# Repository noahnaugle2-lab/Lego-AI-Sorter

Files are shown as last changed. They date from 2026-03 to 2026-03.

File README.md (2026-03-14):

# LEGO AI Sorting Machine v3 / v4 Hybrid

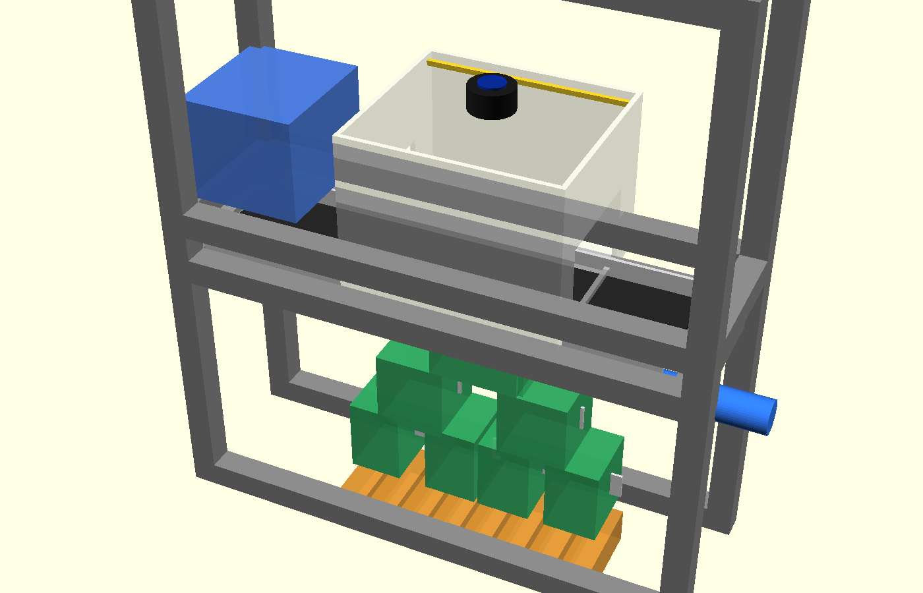
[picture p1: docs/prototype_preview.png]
Prototype Preview


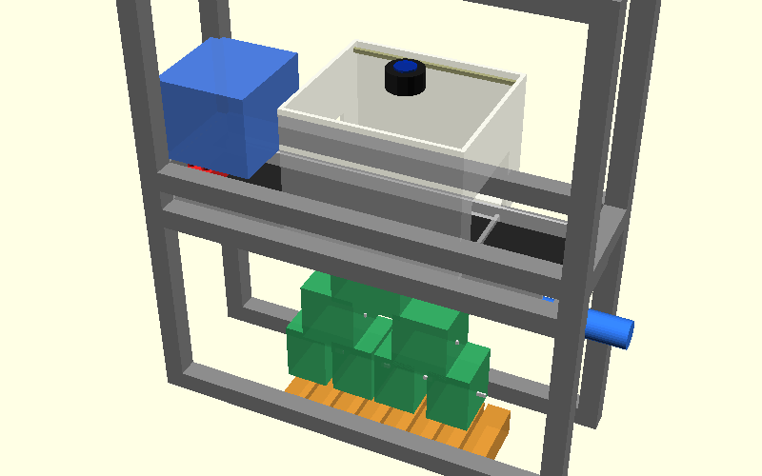
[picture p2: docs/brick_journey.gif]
Brick Journey


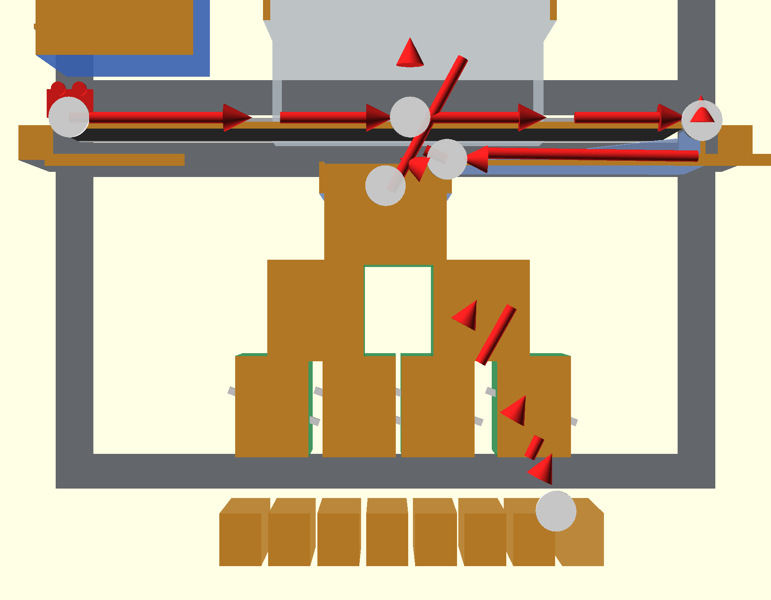
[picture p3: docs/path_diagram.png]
Brick Path Diagram


An AI-powered LEGO brick sorting machine built on a Raspberry Pi 5. Combines computer vision, a Brickognize REST API, a local learning cache, and a binary gate tree to automatically classify and route bricks into output bins in real time.

---

## v4 Hybrid Design

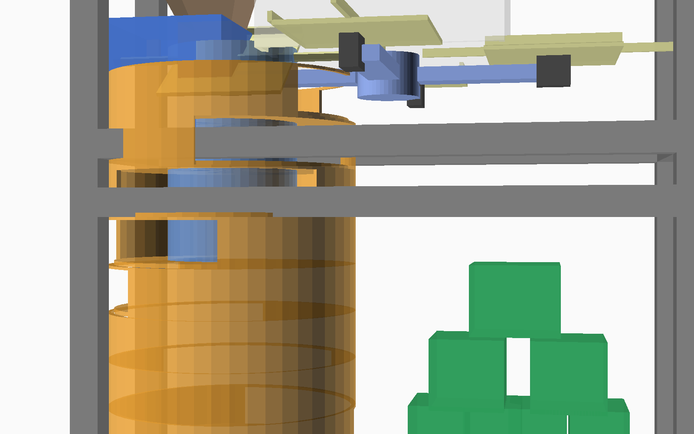
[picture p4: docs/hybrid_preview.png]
Hybrid Assembly Preview


The v4 Hybrid combines the best mechanical ideas from two independent designs into one cohesive machine:

### What's new vs v3

| Subsystem | v3 (original) | v4 Hybrid |
|---|---|---|
| **Input** | Linear NEMA 17 belt | 4-platform rotating carousel |
| **Singulation** | Manual separation | Step feeder hopper (automatic) |
| **Entry transition** | 5.5° gravity ramp (insufficient) | Carousel tilt-to-dispense (active, no ramp) |
| **Distribution** | 31-servo 5-level binary tree (32 bins) | Pancake stack (8 categories) + 3-level mini-tree (8 sub-bins) = 64 destinations |
| **Servo count** | 31 gates | 15 total (4 tilt + 1 trap-door + 10 mini-tree) |
| **Brick size limit** | Informal | 80mm sphere constraint (covers 98% of LEGO production pieces) |

### Carousel Feeder (`carousel.py`, `3d-parts/carousel_feeder.scad`)

A 4-platform rotating carousel replaces the linear belt. All four positions process simultaneously (pipelined):

```
Position 0 — LOAD      ← step feeder deposits one brick
Position 1 — IMAGE     ← fixed camera captures, AI classifies
Position 2 — DISPENSE  ← platform tilts ~45°, brick drops to pancake stack
Position 3 — CLEAR     ← platform returns flat, ready for next brick
```

One 90° rotation advances all platforms by one stage. Effective throughput: ~1 brick per rotation cycle (2–3 s). Each platform has an 80mm × 80mm acrylic insert compatible with the 80mm sphere size constraint that encompasses 98% of production LEGO pieces.

### Pancake Stack Distribution (`pancake_sorter.py`, `3d-parts/pancake_stack.scad`)

A central rotating chute distributes bricks to stacked circular bin levels — one servo per level, one level per category:

```
Level 0 — Bricks    Level 4 — Minifigs
Level 1 — Plates    Level 5 — Slopes
Level 2 — Tiles     Level 6 — Special
Level 3 — Technic   Level 7 — Unknown/Review
```

Below each stack level, a 3-level mini gate tree sub-sorts by part size/variant into 8 output bins. Total: **64 unique destinations** with only **15 servos** (vs 31 in v3).

### What's kept from v3

- Brickognize AI classifier + local HSV histogram cache
- Flask web dashboard + SQLite inventory
- Confidence-based routing (review bin / unknown bin)
- Raspberry Pi 5 target hardware + PCA9685 servo drivers
- All existing sort modes (`part`, `color`, `category`, `set`)

### New files

| File | Purpose |
|---|---|
| `carousel.py` | Carousel feeder motor + platform tilt servos |
| `pancake_sorter.py` | Pancake stack chute + mini gate tree routing |
| `3d-parts/carousel_feeder.scad` | Printable carousel (hub + arms + platforms) |
| `3d-parts/pancake_stack.scad` | Printable bin stack + rotating chute |
| `3d-parts/hybrid_assembly.scad` | Full assembly visualisation |

---

---

## Table of Contents

- [v4 Hybrid Design](#v4-hybrid-design)
- [Quick Start](#quick-start)
- [Architecture Overview](#architecture-overview)
- [Project Structure](#project-structure)
- [Modules & Features](#modules--features)
  - [main.py — Orchestrator](#mainpy--orchestrator)
  - [conveyor.py — Belt Motor Control](#conveyorpy--belt-motor-control)
  - [scanner.py — Camera & Motion Detection](#scannerpy--camera--motion-detection)
  - [classifier.py — AI Classification](#classifierpy--ai-classification)
  - [sorter.py — Binary Gate Tree](#sorterpy--binary-gate-tree)
  - [inventory.py — SQLite Database](#inventorypy--sqlite-database)
  - [web_ui.py — Flask Dashboard](#web_uipy--flask-dashboard)
  - [logger.py — Structured Logging](#loggerpy--structured-logging)
- [Sort Modes](#sort-modes)
- [Confidence Routing](#confidence-routing)
- [Web Dashboard](#web-dashboard)
- [API Reference](#api-reference)
- [Configuration](#configuration)
- [Error Recovery](#error-recovery)
- [Testing](#testing)
- [Hardware Requirements](#hardware-requirements)
- [Auto-Start on Boot](#auto-start-on-boot)

---

## Quick Start

### 1. Install dependencies
```bash
pip install -r requirements.txt --break-system-packages
```

On Raspberry Pi, also install hardware libraries:
```bash
pip install RPi.GPIO adafruit-circuitpython-pca9685 adafruit-circuitpython-motor --break-system-packages
```

### 2. Configure
Edit `config.yaml` to match your hardware:
- GPIO pin numbers for stepper motor and LEDs
- PCA9685 I2C addresses
- Belt speed and encoder settings
- Confidence thresholds
- Bin assignments for part categories
- Sort mode (`part`, `color`, `category`, `set`)

### 3. Test components individually
```bash
# Test camera capture
python main.py --test-camera

# Test classification on a photo
python main.py --test-classify photo_of_brick.jpg

# Test all servo gates
python main.py --test-gates

# Start web dashboard without hardware (simulation mode)
python main.py --web-only

# Start with color sorting mode
python main.py --sort-mode color
```

### 4. Run the full system
```bash
python main.py
```

Web dashboard available at `http://<pi-ip>:5000`

### 5. Run tests
```bash
python -m pytest tests/ -v
```

---

## Architecture Overview

```
Motion Detected
    ↓
[Scanner] Pause Belt → Capture Frames → Select Sharpest → Crop Brick
    ↓
[Classifier] Check Local Cache ──► Cache Hit → Return Cached Result
    ↓ Cache Miss
[Brickognize API] POST JPEG → Parse Response (part_id, color, confidence)
    ↓ Low Confidence (optional rescan)
[Main] Advance Belt → Capture 2nd Angle → Reclassify
    ↓
[Confidence Routing]
  ├─ High (≥0.65) → [Sorter] Binary Gate Tree → Correct Bin
  ├─ Mid  (0.45–0.65) → Review Bin (30)
  └─ Low  (<0.45)     → Unknown Bin (31)
    ↓
[Inventory] Log Part → Update Set Tracking → Hourly Stats
    ↓
[Web Dashboard] Real-time Display & Controls
```

Three threads run concurrently:
- **Main thread**: Flask web server
- **Sorting loop**: Motion → Classify → Sort pipeline
- **Retry loop**: API recovery — reclassifies queued items every 30 seconds

---

## Project Structure
```
lego-sorter/
├── main.py              # Entry point and orchestrator
├── config.yaml          # All configuration and bin assignments
├── conveyor.py          # Stepper motor belt control (with encoder feedback)
├── scanner.py           # Camera capture + motion detection (multi-angle)
├── classifier.py        # Brickognize API + local learning cache
├── sorter.py            # Binary gate tree + multi-sort-mode routing
├── inventory.py         # SQLite database + Rebrickable + analytics + export
├── web_ui.py            # Flask web dashboard + OTA config + REST API
├── logger.py            # Structured JSON logging with file rotation
├── lego-sorter.service  # systemd unit file for auto-start
├── templates/
│   └── dashboard.html   # Responsive single-page dashboard (Bootstrap)
├── tests/
│   ├── test_sorter.py      # Gate tree routing and sort mode tests
│   ├── test_classifier.py  # Cache, confidence, and category tests
│   └── test_inventory.py   # Database, stats, and export tests
├── logs/
│   └── sorter.log       # Rotating JSON log files (auto-created)
├── requirements.txt
└── README.md
```

---

## Modules & Features

### main.py — Orchestrator

The central controller (`SortingMachine` class) that wires all subsystems together.

**Features:**
- Starts and coordinates all subsystems (conveyor, scanner, classifier, sorter, inventory, web UI)
- Manages graceful shutdown on SIGINT/SIGTERM
- **Auto-rescan**: If classification confidence is low, the belt advances slightly and a second image is captured automatically; tracks rescan success rate
- **API Retry Queue**: Holds up to 20 failed classifications in memory; a background thread retries every 30 seconds when the API recovers
- **OTA Configuration**: Applies runtime config changes (belt speed, thresholds, LED brightness) from the web dashboard without restarting
- **Power Sequencing**: Controls servo power relay via GPIO 22 (enabled on init, disabled on shutdown to prevent brown-out)
- Simulation mode: All hardware interfaces fall back to no-ops when RPi libraries are unavailable

---

### conveyor.py — Belt Motor Control

Controls the conveyor belt stepper motor with optional closed-loop feedback.

**Features:**
- Drives a **NEMA 17 stepper motor** via a **TMC2209** driver (step/dir/enable GPIO pins)
- Configurable belt speed (5–100 mm/s), dynamically adjustable at runtime
- **Closed-loop encoder feedback** (optional):
  - Reads a rotary encoder (channels A/B) via GPIO interrupts
  - Measures actual belt speed from pulses-per-revolution and roller circumference
  - Proportional speed correction (Kp = 0.3) adjusts step delays every 250 ms
- **Pause/Resume**: Stops belt during scanning, resumes after classification (configurable pause delay, default 300 ms)
- Thread-safe pause/resume lock for coordination with sorting loop

---

### scanner.py — Camera & Motion Detection

Handles image capture, motion detection, and brick isolation.

**Features:**
- Supports **Pi Camera Module 3** (primary, up to 1920×1080) and an optional secondary USB camera for multi-angle classification
- **Motion detection**: Frame differencing with Gaussian blur and pixel threshold — triggers belt pause and capture when a brick enters the scanning chamber
- **Background reference frame**: Captured at startup and refreshable via the dashboard API (`/api/control/update_background`)
- **Best-frame selection**: Captures a configurable number of frames and selects the sharpest using Laplacian variance
- **Auto-exposure warmup**: Discards first 30 frames at startup to stabilize camera exposure
- **Brick cropping**: Contour detection with configurable padding to isolate the brick in the frame
- **LED control**: PWM-controlled LED strip (GPIO 12, 1000 Hz) with configurable brightness (0–100%)
- **MJPEG streaming**: Provides live video feed endpoints for the web dashboard

---

### classifier.py — AI Classification

Identifies bricks using the Brickognize REST API and a local learning cache.

**Brickognize API:**
- POSTs JPEG images to `https://api.brickognize.com/predict/`
- Returns: `part_id`, `part_name`, `color`, `confidence` (0–1), and up to 3 alternative matches
- Timeout: 10 seconds; 2 automatic retries on failure with 1-second delays
- Supports multi-angle classification (secondary image improves confidence)

**Local Learning Cache:**
- Avoids API calls for previously seen bricks
- Signature: **HSV color histogram** (8×8×4 bins, 256 buckets) + **aspect ratio**
- Similarity: Bhattacharyya coefficient (70% histogram + 30% aspect ratio)
- **Auto-learns** API results with confidence ≥ 0.85
- **Manual corrections** from the Review tab stored with confidence = 1.0
- Persistence: JSON file on disk; FIFO eviction when cache exceeds 200 entries
- Match threshold: 0.90 similarity required to use a cached result

**Confidence Routing:**
- High (≥ 0.65): Auto-sort to correct bin
- Mid (0.45–0.65): Route to review bin (30) for human verification
- Low (< 0.45): Route to unknown bin (31)

**Category Extraction:**
- 65 keyword patterns covering detailed LEGO taxonomy (bricks, plates, tiles, technic, slopes, arches, etc.)
- Specificity-ordered matching (e.g., "Brick 2x4" matched before generic "Brick")
- Fallback: "Other" category for unrecognized parts

**Statistics tracked:** total classifications, successes, failures, review count, accuracy rate, cache hits/misses

---

### sorter.py — Binary Gate Tree

Routes bricks through a physical binary gate tree into one of 32 bins.

**Hardware:**
- **31 servo gates** across **2× PCA9685** 16-channel PWM boards (I2C: 0x40, 0x41)
- Top 3 levels (7 gates): **MG90S** metal-gear servos (higher torque, durable)
- Bottom 2 levels (24 gates): **SG90** micro servos (cost-effective)
- Configurable pulse widths per servo type and settle time (default 120 ms)

**Gate Tree:**
- 5-level binary tree: Level 0 (root, 1 gate) → Level 4 (16 gates) = 31 total gates, 32 leaf bins
- Routing: Binary decomposition of the bin number determines left/right path at each level
- Gates 0–15 on board 1, gates 16–30 on board 2

**Sort Modes:**
| Mode | Routing Logic |
|---|---|
| **Part** (default) | Keyword-matched part type → `bin_assignments` in config |
| **Color** | `COLOR_BIN_MAP` — 32 named colors mapped to specific bins |
| **Category** | Broad groups: bricks→0, plates→1, tiles→2, technic→4, slopes→5, etc. |
| **Set** | Parts needed for a target LEGO set get priority bins; others go to overflow |

**Bin Management:**
- Per-bin part count tracking; warns at 50+ items per bin
- Gate actuation counter per gate; logs maintenance warning at 10,000 actuations
- Individual or full bin reset via dashboard API

---

### inventory.py — SQLite Database

Persistent storage for all sort history, analytics, and set tracking.

**Database Tables:**
| Table | Purpose |
|---|---|
| `sorted_parts` | Full history: part_id, name, color, bin, confidence, timestamp |
| `set_inventories` | Rebrickable set part lists (part_id, color, quantity needed/found) |
| `sets` | Set metadata: name, year, total part count |
| `sort_history` | Hourly aggregated counts for analytics charts |
| `corrections` | Reclassification feedback log (old bin → new bin) |

**Statistics:**
- Total sorted, identified, unique parts, average confidence
- Throughput: parts/minute (last 10 min), parts/hour, parts/day, peak hour, session duration
- Confidence distribution histogram (10 buckets, 0–100%)
- Top 10 categories and top 10 colors (last 10 entries)
- Review parts list (needs_review flag)

**Rebrickable Integration:**
- Fetches set part lists via paginated Rebrickable API (100 parts/page)
- Tracks parts found vs. quantity needed per set
- Reports completion percentage per target set

**Export Formats:**
- **BrickLink CSV**: Part ID, Color, Quantity
- **Rebrickable CSV**: Part, Color, Quantity
- **Missing Parts CSV**: Parts still needed to complete a specific set

---

### web_ui.py — Flask Dashboard

Single-page web application for monitoring and controlling the machine.

**Dashboard Tab:**
- Live MJPEG camera feed (primary + optional secondary)
- Current machine state: running / idle / classifying / scanning / sorting
- Recent 30 sorted parts with part name, color, bin, and timestamp
- Real-time stats: total sorted, identified, unique parts, accuracy
- Bin status panel: highlights bins at or above capacity (≥50 items)
- Set tracking: shows completion progress for target LEGO sets
- Controls: Start / Stop / Pause / Resume
- Belt speed slider (5–100 mm/s)
- Sort mode selector (Part / Color / Category / Set)
- Inventory CSV export button

**Analytics Tab:**
- Throughput metrics: last-hour count, 24-hour count, peak hour, avg/hour, session duration
- Sort history bar chart: hourly counts over the last 24 hours
- Confidence distribution histogram
- Top 10 categories and top 10 colors

**Review Tab:**
- Lists all parts flagged for manual verification
- Sortable by part name, confidence, or timestamp
- One-click bin reassignment — feedback is saved to the local learning cache

**Settings Tab:**
- Belt speed, confidence threshold, review threshold, LED brightness
- Changes applied live and persisted to `config.yaml` (no restart required)
- Sensitive keys (API keys, secrets) are protected from web-based editing

---

### logger.py — Structured Logging

**Features:**
- Hierarchical loggers: root `sorter` with per-module children (`sorter.classifier`, etc.)
- Console output: color-coded by level (DEBUG cyan, INFO green, WARNING yellow, ERROR red)
- File output: JSON-formatted entries for machine parsing
- Rotating file handler: 5 MB per file, 5 backup files, written to `logs/sorter.log`
- Contextual metadata fields: `part_id`, `confidence`, `bin_number`, `category`, `color`, etc.
- Auto-creates `logs/` directory on first run

---

## Sort Modes

Switchable at runtime from the dashboard or via `--sort-mode` CLI flag:

| Mode | Description |
|---|---|
| **part** | Routes by specific part type using `bin_assignments` keyword map in `config.yaml` |
| **color** | Routes by color name using a 32-color → bin mapping |
| **category** | Routes by broad category group (bricks, plates, tiles, technic, slopes, etc.) |
| **set** | Prioritizes parts needed for a target LEGO set into dedicated bins; overflow to general bins |

---

## Confidence Routing

Every classified brick is routed based on API confidence score:

| Confidence | Destination |
|---|---|
| ≥ 0.65 | Auto-sorted to the correct bin |
| 0.45 – 0.65 | Review bin (30) — appears in Review tab for manual reclassification |
| < 0.45 | Unknown bin (31) — catch-all for unrecognized parts |

Thresholds are configurable in `config.yaml` and adjustable live from the Settings tab.

---

## Web Dashboard

Access at `http://<pi-ip>:5000` after starting the machine.

---

## API Reference

All endpoints return JSON unless noted.

### Stats & Data
| Endpoint | Method | Description |
|---|---|---|
| `/api/stats` | GET | Overall stats: totals, accuracy, throughput, bin status |
| `/api/recent` | GET | Last 30 sorted parts |
| `/api/review` | GET | Parts in review bin needing reclassification |
| `/api/sets` | GET | Target set completion progress |
| `/api/sort_history` | GET | Hourly sort counts (last 24 hours) |

### Controls
| Endpoint | Method | Description |
|---|---|---|
| `/api/control/start` | POST | Start sorting loop |
| `/api/control/stop` | POST | Stop sorting loop |
| `/api/control/pause` | POST | Pause belt |
| `/api/control/resume` | POST | Resume belt |
| `/api/control/speed` | POST | Set belt speed (mm/s) |
| `/api/control/sort_mode` | POST | Switch sort mode |
| `/api/control/test_bin` | POST | Route a test part to a specific bin |
| `/api/control/test_gates` | POST | Cycle all servo gates for testing |
| `/api/control/update_background` | POST | Refresh motion detection background frame |

### Classification
| Endpoint | Method | Description |
|---|---|---|
| `/api/reclassify/<id>` | POST | Reassign a part to a different bin; stores correction in cache |

### Export
| Endpoint | Method | Description |
|---|---|---|
| `/api/export/inventory` | GET | Download full inventory as BrickLink CSV |
| `/api/export/rebrickable` | GET | Download inventory as Rebrickable CSV |
| `/api/export/missing/<set_num>` | GET | Download missing parts for a specific set |

### Configuration
| Endpoint | Method | Description |
|---|---|---|
| `/api/config` | GET | Get current editable config values |
| `/api/config` | POST | Update config values (applied live + saved to config.yaml) |

### Video
| Endpoint | Description |
|---|---|
| `/video_feed` | Primary MJPEG camera stream |
| `/video_feed_secondary` | Secondary camera MJPEG stream |

---

## Configuration

All settings are in `config.yaml`:

```yaml
belt:
  step_pin: 17          # GPIO step signal
  dir_pin: 27           # GPIO direction signal
  enable_pin: 22        # GPIO enable (active-low)
  speed_mm_s: 30        # Belt speed in mm/s
  encoder:
    enabled: false
    pin_a: 23
    pin_b: 24
    ppr: 600            # Pulses per revolution
    roller_diameter_mm: 20

scanner:
  camera_index: 0
  resolution: [1920, 1080]
  capture_frames: 5     # Frames to capture; sharpest selected
  motion_threshold: 500 # Pixel change threshold for motion detection
  led_pin: 12           # PWM LED control pin

classifier:
  api_url: "https://api.brickognize.com/predict/"
  confidence_threshold: 0.65
  review_threshold: 0.45
  cache:
    enabled: true
    max_size: 200
    learn_threshold: 0.85

sorter:
  i2c_addresses: [0x40, 0x41]
  sort_mode: part       # part | color | category | set
  gate_settle_ms: 120
  bin_assignments:
    brick: 0
    plate: 1
    # ... (customize per your bin layout)

rebrickable:
  api_key: ""
  target_sets: []

web:
  host: "0.0.0.0"
  port: 5000
  debug: false
```

---

## Error Recovery

| Failure | Recovery Behavior |
|---|---|
| Brickognize API down | Up to 20 items queued in memory; background thread retries every 30 s |
| Camera unavailable | Falls back to dummy frame in simulation mode |
| Low confidence | Auto-rescan: belt advances, second image captured and reclassified |
| Database table missing | Tables recreated automatically on startup |
| Hardware unavailable | Full simulation mode — all GPIO/I2C calls are no-ops |

---

## Testing

```bash
python -m pytest tests/ -v
```

| Test Module | Coverage |
|---|---|
| `test_classifier.py` | LocalCache (learn, match, eviction, persistence), histogram correlation edge cases, category extraction for 6+ part types |
| `test_sorter.py` | Gate tree routing (31 gates, 32 bins), bin counting and warnings, MG90S vs SG90 assignment, all 4 sort modes, invalid input rejection, gate usage tracking |
| `test_inventory.py` | log_part, get_stats, recent_parts ordering, reclassification with correction logging, review parts filtering, BrickLink/Rebrickable CSV export, confidence histogram, hourly sort aggregation |

---

## Hardware Requirements

| Component | Details |
|---|---|
| Raspberry Pi 5 | 8 GB RAM recommended |
| Camera | Pi Camera Module 3 (primary); optional USB camera for side view |
| Stepper Motor | NEMA 17 + TMC2209 driver |
| Servos — top 3 levels | 7× MG90S metal-gear |
| Servos — bottom 2 levels | 24× SG90 micro |
| PWM boards | 2× PCA9685 16-channel (I2C) |
| Lighting | LED strip + MOSFET |
| Encoder | Optional rotary encoder for closed-loop belt speed |

See `docs/Design_Document_Expanded.docx` for the full bill of materials and `docs/wiring_diagram.html` for wiring details.

---

## Auto-Start on Boot

```bash
sudo cp lego-sorter.service /etc/systemd/system/
sudo systemctl daemon-reload
sudo systemctl enable lego-sorter
sudo systemctl start lego-sorter

# View live logs
sudo journalctl -u lego-sorter -f

# Parse JSON log files
cat logs/sorter.log | python -m json.tool
```

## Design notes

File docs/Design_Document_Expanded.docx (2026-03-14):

LEGO AI Sorting Machine

Complete System Design Document

Final Design — All Decisions Locked

Platform: Raspberry Pi 5 (8GB)

Classification: Brickognize API

Sorting: 32-Bin Binary Gate Tree

Frame: 2020 Aluminum Extrusion + 3D-Printed Brackets

Manual Feed (user places bricks on belt)

March 2026

# 1. Project Overview

This document is the finalized design specification for an AI-powered LEGO brick sorting machine. The system uses a Raspberry Pi 5, a single camera with an angled mirror, and the Brickognize API to identify individual LEGO parts by part number and color. Identified bricks are routed through a 5-level binary gate tree into 32 output bins. The operator places bricks onto a slow-moving wide belt by hand, eliminating the need for a complex automated feeder.

## 1.1 Design Goals

- Identify any standard LEGO brick by part number and color using the Brickognize API
- Sort at approximately 1 brick every 3–5 seconds
- 32 output bins via a 5-level binary gate tree (31 servo-controlled gates)
- Cross-reference identified parts against set inventories via Rebrickable API
- Frame built from 2020 aluminum extrusion with 3D-printed brackets and functional parts
- Manual feed: operator places bricks on a wide flat belt

## 1.2 Key Design Decisions (Locked)

Decision | Choice | Rationale
Classification | Brickognize API | Free, covers 80,000+ parts, no training needed, handles the reality gap problem that plagues custom models
Sorting Mechanism | Binary gate tree (32 bins) | Silent, gravity-fed, no compressed air, scales cleanly, 31 cheap SG90 servos
Camera Setup | Single camera + 45° mirror | Two viewing perspectives (top-down + side profile) from one camera, zero extra Pi resources, proven by BrickSortingMachine project
Belt | Wide flat silicone/rubber (~70mm) | Easy for manual brick placement, forgiving, comfortable working surface
Frame | 2020 aluminum extrusion + 3D-printed brackets | Strong, modular, adjustable, easy to iterate, widely available
Feeding | Manual (user places bricks) | Eliminates the hardest subsystem (hopper/vibration feeder), saves months of debugging
Computer | Raspberry Pi 5 (8GB) | Sufficient for camera capture, motor control, API calls, and web dashboard
Printer | 256mm build plate (Prusa/Bambu) | All parts designed to fit this bed size without splitting

# 2. System Architecture

The machine consists of five interconnected stages: a slow-moving conveyor belt for manual loading, a scanning chamber with controlled lighting and a camera/mirror setup, the Raspberry Pi 5 running the classification pipeline, a binary gate tree for physical sorting, and a software layer that ties everything together with inventory tracking and a web dashboard.

Operational Flow: User places brick on belt → Belt carries brick into scanning chamber → Motion detected, belt pauses → Camera captures image (top-down + mirror side view) → Image sent to Brickognize API → Part ID + color returned → Gate tree servos set to correct path → Belt resumes → Brick falls through gate tree into correct bin → Part logged to inventory → Repeat.

## 2.1 Stage 1: Conveyor Belt (Manual Feed)

A single wide flat belt running at approximately 30–40 mm/s. The operator stands at one end and places bricks with a gap between each. The belt carries them into the scanning chamber approximately halfway along its length.

Specifications

- Belt width: ~70mm (accommodates largest standard bricks with margin)
- Belt material: Silicone or polyurethane flat belt, smooth surface
- Belt length: ~500mm (enough working room for placement + scanning + exit)
- Drive: 1x NEMA 17 stepper motor with a 3D-printed drive roller (25mm diameter)
- Rollers: 3D-printed with 608 bearings (2 per roller, 4 total for drive + idler)
- Side rails: Low 3D-printed walls (~15mm tall) through the scanning zone to keep bricks centered
- Tensioning: Spring-loaded idler roller at the feed end for consistent belt tension
- Frame: 2020 aluminum extrusion rails, belt assembly mounts via printed brackets

Motor Control

The stepper motor is driven by a TMC2209 silent stepper driver. The Pi 5 sends STEP/DIR signals via GPIO. The belt pauses when a brick is detected in the scanning chamber (motion detection via OpenCV) and resumes after classification is complete and gates are set. Belt speed is configurable via the web dashboard.

## 2.2 Stage 2: Scanning Chamber

An enclosed 3D-printed box mounted over the belt, painted matte white inside, with diffused LED lighting and a camera/mirror configuration that captures two perspectives of each brick simultaneously.

Camera + Mirror Setup

A Raspberry Pi Camera Module 3 (12MP, autofocus) is mounted directly above the belt, looking straight down. A 45-degree angled mirror is mounted on the far wall of the chamber, opposite the camera. This mirror reflects a side profile of the brick upward into the camera frame. The result is a single captured image containing both a top-down view and a side profile view of the brick.

This dual-perspective approach significantly improves classification accuracy. Many parts (e.g., 2x4 brick vs. 2x4 plate) are indistinguishable from above but have clearly different height profiles. The Brickognize API accepts this type of composite image.

Lighting

A ring of diffused white LEDs mounted inside the chamber provides even, shadow-free illumination. The LEDs are driven at constant current via a small LED driver board, with brightness adjustable via PWM from the Pi. The enclosed chamber blocks ambient light variation, ensuring consistent image quality regardless of room lighting.

Chamber Dimensions

- Interior: approximately 120mm wide x 120mm deep x 100mm tall
- The belt passes through slots in the left and right walls
- Camera is mounted on top via an adjustable bracket
- Mirror is mounted on the far interior wall at 45 degrees
- All interior surfaces are matte white (painted or white PLA/PETG)
- Printed in 2–3 pieces to fit the 256mm build plate

## 2.3 Stage 3: AI Classification (Brickognize API)

Rather than training a custom neural network (which requires weeks of work, synthetic data generation, and still struggles with the sim-to-real gap), this design uses the Brickognize API, a free web service that can identify over 80,000 LEGO parts, sets, and minifigures from a photograph.

Classification Pipeline

1. Motion detection (OpenCV frame differencing) triggers when a brick enters the scanning chamber
2. Belt pauses for approximately 200ms to allow a sharp capture
3. Camera captures 3–5 frames; the sharpest is selected
4. Background subtraction isolates the brick from the white chamber background
5. Image is cropped and sent to the Brickognize API via HTTP POST
6. API returns: part ID, part name, color, confidence score, and alternative matches
7. If confidence is above threshold (e.g., 70%), the brick is routed to its assigned bin
8. If confidence is below threshold, the brick goes to the "unknown" bin for manual review
9. Part is logged to the local inventory database

API Details

Endpoint: POST https://api.brickognize.com/predict/ with the image as multipart form data. The response is JSON containing the top predictions ranked by confidence. Latency is typically 500ms–1500ms depending on connection quality. The system requires WiFi connectivity on the Pi 5.

Color Detection

Brickognize returns color information as part of its prediction. For additional accuracy, the system also performs local HSV color space analysis on the cropped brick region and maps to LEGO’s official color palette. This dual approach (API color + local HSV) provides a cross-check.

## 2.4 Stage 4: Binary Gate Tree (32-Bin Sorting)

After classification, the brick falls off the end of the belt into a gravity-fed binary gate tree. This is a vertical structure of Y-junction chutes, each containing a servo-controlled flap that directs the brick left or right. With 5 levels of binary decisions, the tree provides 2^5 = 32 unique output paths.

Gate Tree Layout

Level | Number of Gates | Cumulative Paths
1 | 1 gate | 2 paths
2 | 2 gates | 4 paths
3 | 4 gates | 8 paths
4 | 8 gates | 16 paths
5 | 16 gates | 32 paths (output bins)
Total | 31 gates | 32 bins

Mechanical Design

- Each gate is a 3D-printed Y-junction module with a pivoting flap actuated by an SG90 micro servo
- Modules are designed as snap-fit modular units; if one breaks, it can be replaced individually
- The tree is angled at approximately 30 degrees from vertical so bricks slide through by gravity
- Each Y-junction is approximately 60mm wide x 40mm deep x 50mm tall
- Total tree height: approximately 350–400mm across 5 levels
- All 31 modules are identical in design, simplifying printing (print 31 copies of one STL)

Servo Control

The 31 servos are driven by 2x PCA9685 16-channel PWM servo driver boards connected to the Pi 5 via I2C (addresses 0x40 and 0x41). When a classification result comes in, all 5 gates on the correct path are set simultaneously before the brick enters the tree. Switching time is approximately 100ms per servo, well within our throughput window. Servos are powered by a dedicated 5V 10A power supply, separate from the Pi’s supply.

## 2.5 Stage 5: Control Software

All software runs on the Raspberry Pi 5 under Raspberry Pi OS (64-bit Bookworm). The system is orchestrated by a Python application with modular components.

Software Architecture

Module | Responsibility | Key Libraries
main.py | Orchestrator: runs the main loop, coordinates all subsystems | asyncio
conveyor.py | Stepper motor control: start, stop, speed adjustment | RPi.GPIO or gpiozero
scanner.py | Camera capture, motion detection, image selection | OpenCV, picamera2
classifier.py | Sends images to Brickognize API, parses results | requests, Pillow
sorter.py | Gate tree routing logic, servo positioning via PCA9685 | adafruit-circuitpython-pca9685
inventory.py | SQLite parts database, Rebrickable API integration | sqlite3, requests
web_ui.py | Flask web dashboard: live stats, camera feed, controls | Flask, flask-socketio
config.yaml | Bin assignments, speed settings, confidence thresholds | PyYAML

Operational Loop

10. Belt runs at configured speed (~35mm/s)
11. OpenCV motion detection monitors the scanning chamber continuously
12. Brick detected: belt pauses, camera captures frames
13. Sharpest frame selected, background subtracted, brick cropped
14. Cropped image POSTed to Brickognize API
15. Response parsed: part_number, color, confidence
16. Bin assignment looked up from config (part_number to bin_id mapping)
17. 5 gate servos set to route brick to assigned bin
18. Belt resumes; brick falls through gate tree into bin
19. Part logged to SQLite database; web dashboard updated via WebSocket

Rebrickable Integration

On startup, the system pulls full parts inventories for the user’s target LEGO sets via the Rebrickable API. As parts are identified and sorted, they are marked off against set inventories in real time. The web dashboard displays set completion progress (e.g., “Set 42100: 347/892 parts found, 12 missing, 533 not yet sorted”). Missing parts can be exported as a BrickLink-format CSV for ordering.

Web Dashboard

- Live camera feed from the scanning chamber
- Real-time statistics: bricks sorted, bricks/minute, classification confidence histogram
- Set completion progress bars for each registered set
- Manual override: re-classify or re-route a brick
- Bin assignment editor (change which part types route to which bins)
- Start / Stop / Pause controls
- Accessible from any device on the local network via browser

# 3. Frame and Structure

## 3.1 Aluminum Extrusion Frame

The frame is built from 2020 aluminum extrusion (20mm x 20mm T-slot profile). This provides a rigid, modular, and adjustable structure. All functional components (belt assembly, scanning chamber, gate tree, electronics enclosure) attach to the extrusion via 3D-printed brackets that slide into the T-slots and clamp with M5 T-nuts and bolts.

Frame Dimensions (approximate)

- Overall width: ~400mm
- Overall depth: ~350mm
- Overall height: ~700mm (belt at top, gate tree descending, bins at bottom)
- The belt section sits at approximately 600mm height for comfortable manual loading while standing
- The gate tree extends downward from the belt exit to the bin array at the base

Extrusion Cut List

Piece | Length | Quantity | Purpose
Vertical uprights | 700mm | 4 | Main structural columns
Upper horizontal (width) | 400mm | 2 | Belt support, top frame
Upper horizontal (depth) | 350mm | 2 | Belt support, cross-bracing
Lower horizontal (width) | 400mm | 2 | Bin tray support
Lower horizontal (depth) | 350mm | 2 | Bin tray support
Mid horizontal (depth) | 350mm | 2 | Gate tree mounting

Total 2020 extrusion needed: approximately 7.2 meters. A 1-meter 6-pack is the most economical way to purchase this.

## 3.2 3D-Printed Parts List

All parts are designed to fit a 256mm x 256mm build plate. Material recommendation: PETG for functional parts (gate modules, belt rollers) and PLA for non-structural parts (brackets, enclosures, chamber).

Part | Qty | Est. Print Time | Material | Notes
Belt drive roller (25mm dia) | 1 | 1.5 hrs | PETG | Press-fit 608 bearing bores
Belt idler roller (25mm dia) | 1 | 1.5 hrs | PETG | Spring-tensioned mount
Roller bearing housings | 4 | 2 hrs | PETG | Mount to extrusion via T-nut brackets
NEMA 17 motor mount | 1 | 1 hr | PETG | Attaches to extrusion upright
Belt side rails (pair) | 2 | 1 hr | PLA | 15mm tall, clip onto extrusion
Scanning chamber (2–3 pieces) | 1 set | 5 hrs | PLA (white) | Matte white interior, snap-fit assembly
Camera mount bracket | 1 | 0.5 hr | PLA | Adjustable height, mounts on chamber top
Mirror mount (45° angle) | 1 | 0.5 hr | PLA | Holds ~50mm mirror at precise angle
Y-junction gate modules | 31 | 22 hrs | PETG | Modular snap-fit; print in batches of 8
Gate flap inserts | 31 | 4 hrs | PLA | Lightweight pivoting flaps
Servo mount clips | 31 | 3 hrs | PETG | Snap onto Y-junction modules
Gate tree frame brackets | 12 | 3 hrs | PETG | Connect gate tree to extrusion frame
Extrusion corner brackets | 16 | 3 hrs | PLA | 90° frame joints
Electronics enclosure | 1 | 3 hrs | PLA | Houses Pi 5 + driver boards, ventilated
PCA9685 mount plates | 2 | 0.5 hr | PLA | Mount inside electronics enclosure
Output bin brackets | 8 | 2 hrs | PLA | Hold standard plastic bins under gate tree
Belt tensioner bracket | 1 | 0.5 hr | PETG | Spring-loaded idler mechanism

Total estimated print time: approximately 54 hours

Total filament: approximately 1.5 kg PETG + 0.5 kg PLA

# 4. Wiring and Electronics

## 4.1 Wiring Schematic

Pi 5 Connection | Destination | Notes
CSI ribbon cable | Pi Camera Module 3 | 12MP, autofocus, wide-angle
GPIO 2, 3 (I2C SDA/SCL) | PCA9685 #1 (addr 0x40) | Servos 0–15
I2C daisy-chain | PCA9685 #2 (addr 0x41) | Servos 16–30
GPIO 17 (STEP) | TMC2209 stepper driver | Belt motor step signal
GPIO 18 (DIR) | TMC2209 stepper driver | Belt motor direction
GPIO 12 (PWM) | LED driver / MOSFET | Scanner LED brightness
GPIO 25 (input) | IR break-beam sensor (optional) | Brick-at-exit detection
USB-C | 5V 5A power supply | Pi power

Power Distribution

- 5V 10A power supply: dedicated to servo power via PCA9685 V+ terminals
- 12V 2A power supply: stepper motor power via TMC2209 VMOT
- 5V 5A USB-C supply: Raspberry Pi 5 power
- LED strip: powered from 5V servo supply via MOSFET controlled by Pi PWM

All three supplies share a common ground. The servo supply must be robust (10A) because all 31 servos could potentially move simultaneously during path setup, though typical draw is much lower.

# 5. Bill of Materials

## 5.1 Electronics

Component | Qty | Est. Cost | Notes
Raspberry Pi 5 (8GB) | 1 | Owned | Main controller
Pi Camera Module 3 (wide) | 1 | $25 | 12MP, autofocus
NEMA 17 stepper motor | 1 | $10 | Belt drive, 1.8°/step
TMC2209 stepper driver | 1 | $5 | Silent operation
SG90 micro servos | 31 | $40 | Gate tree actuators (~$1.30 each bulk)
PCA9685 servo driver boards | 2 | $8 | 16-ch PWM, I2C stackable
LED strip (white, 30cm) | 1 | $5 | Scanner illumination
MOSFET module (IRLZ44N) | 1 | $2 | LED PWM control
5V 10A power supply | 1 | $15 | Servo power
12V 2A power supply | 1 | $8 | Stepper power
5V 5A USB-C supply | 1 | $12 | Pi power (if not already owned)
Logic level converter | 1 | $2 | 3.3V Pi to 5V servo signals
IR break-beam sensor | 1 | $3 | Optional: brick exit detection
Wiring, connectors, crimp pins | 1 kit | $12 | JST, Dupont, misc
Small mirror (~50x50mm) | 1 | $3 | Scanning chamber side view

Electronics subtotal: approximately $150 (excluding Pi 5 already owned)

## 5.2 Mechanical / Structural

Component | Qty | Est. Cost | Notes
2020 aluminum extrusion | ~7.2m total | $30 | 6-pack of 1m lengths
M5 T-nuts + bolts kit | 1 kit (50pc) | $10 | Frame assembly hardware
M3 hardware assortment | 1 kit | $8 | Servo mounts, brackets, misc
Flat silicone belt (~70mm wide) | 0.6m | $8 | Belt surface; or polyurethane
608 bearings (8x22x7mm) | 4 | $4 | Belt rollers
Small extension spring | 2 | $3 | Belt tensioner
3D printer filament (PETG) | 1.5 kg | $30 | Functional parts
3D printer filament (PLA) | 0.5 kg | $10 | Brackets, enclosures
Output bins (small plastic) | 8–16 | $10–20 | Reuse containers or buy a set
M2 screws (for servos) | 1 kit | $3 | SG90 mounting

Mechanical subtotal: approximately $120–$130

TOTAL ESTIMATED COST: approximately $270–$280 (excluding Pi 5 and 3D printer)

# 6. Build Sequence

The build is divided into five phases. Each phase produces a testable subsystem, so you get working results early and can catch problems before committing to the full assembly.

## Phase 1: Scanner + Classifier (Week 1–2)

Build the scanning chamber, mount the camera and mirror, connect to the Pi 5, and write the image capture and Brickognize API integration. Test by manually placing bricks inside the chamber and verifying that the API returns correct part identifications. This proves the hardest conceptual piece ("can the system actually recognize my bricks?") before any mechanical construction.

Deliverables

- 3D-printed scanning chamber assembled and painted white inside
- Camera + mirror mounted and aligned
- LED lighting installed and tested
- Python scanner.py and classifier.py working end-to-end
- Test batch of 50+ bricks identified with accuracy log

## Phase 2: Belt Assembly (Week 2–3)

Cut aluminum extrusion to length, assemble the frame, print and install the belt rollers, mount the stepper motor, and install the flat belt. Integrate with the scanning chamber. Test brick flow: place a brick on the belt, have it travel into the scanner, pause, classify, and resume.

Deliverables

- Aluminum frame assembled (at least upper section)
- Belt running smoothly with manual brick placement
- Stepper motor controlled by Pi via TMC2209
- Motion detection triggering belt pause and image capture
- End-to-end: place brick → belt carries to scanner → classified → belt resumes

## Phase 3: Gate Tree (Week 3–4)

Print all 31 Y-junction gate modules and flap inserts. Assemble the 5-level binary tree structure and mount it below the belt exit on the aluminum frame. Wire all 31 servos to the PCA9685 boards. Test routing: send a known classification and verify the brick falls into the correct bin.

Deliverables

- All 31 gate modules printed, assembled with servos
- Gate tree mounted on frame, all bins accessible
- PCA9685 boards wired and tested (every gate routes correctly)
- Sorting logic verified: each of 32 bin paths works

## Phase 4: Full Integration (Week 4–5)

Connect all subsystems. Run the full pipeline end-to-end: place brick on belt, belt carries to scanner, API identifies, gates set, belt resumes, brick drops into correct bin, part logged. Tune belt speed, capture timing, and confidence thresholds.

Deliverables

- Complete system running autonomously (after initial brick placement)
- Web dashboard live on local network
- Bin assignment configuration finalized for the user’s most common parts
- Timing optimized for consistent throughput

## Phase 5: Inventory + Calibration (Ongoing)

Register target LEGO sets via Rebrickable. Run sorting sessions and track set completion progress. Review and manually sort the "unknown" bin. Adjust bin assignments as patterns emerge. Export missing parts lists for ordering.

Deliverables

- Rebrickable set inventories loaded
- Set completion tracking working on dashboard
- Missing parts export to BrickLink/Pick-a-Brick CSV
- Unknown bin review workflow established

# 7. Lessons Learned from Prior Builds

This design incorporates findings from multiple documented LEGO sorting machine projects, including Daniel West’s Universal LEGO Sorting Machine, the NAU capstone project by Pisciotta/Shorr/Vigueria, the BrickSortingMachine project, LegoSpencer’s build, and the IEEE Spectrum 2-ton sorter by Jacques Mattheij.

Key takeaways applied to this design:

- The automated feeder/hopper is the hardest subsystem across every project. Manual feed eliminates this entirely.
- The Brickognize API removes the need for custom model training, avoiding the sim-to-real accuracy gap that plagued multiple projects.
- Controlled, enclosed lighting is essential for consistent image quality. Our white-painted scanning chamber with diffused LEDs addresses this.
- Multiple viewing angles dramatically improve classification accuracy. The angled mirror approach gives two perspectives with zero added computational cost.
- The NAU team’s Raspberry Pi 3 hit RAM limits at 50–70% utilization with local image recognition. By offloading classification to Brickognize, our Pi 5 stays light.
- Belt side rails prevent edge bricks from falling off or entering the scanner misaligned. Confirmed important by both NAU and Garcia builds.
- Modular gate/bin designs allow replacement of individual broken parts without disassembly.
- Starting with the scanner/classifier before building mechanical systems proves viability early and prevents wasted effort.

# 8. Next Steps

With all design decisions locked, the following deliverables can be produced:

20. 3D-printable STL files: scanning chamber, gate modules, brackets, rollers, enclosures
21. Full Python codebase: camera capture, Brickognize integration, motor control, gate routing, web dashboard
22. Detailed wiring diagram (Fritzing or KiCad schematic)
23. Aluminum extrusion cut list with assembly instructions
24. Configuration guide: bin assignments, Rebrickable API setup, dashboard usage

# 9. Troubleshooting Guide

This section covers the most common issues encountered during assembly, calibration, and daily operation of the sorting machine, along with proven solutions.

## 9.1 Belt Issues

Belt drifts to one side: The drive and idler rollers are not parallel. Loosen the idler bearing mounts and adjust the tensioner bracket until the belt tracks centrally. The crowned roller profile helps self-correct minor misalignment, but persistent drift means the frame is slightly racked. Check that the aluminum extrusion upper horizontals are square using a machinist’s square.

Belt slips on drive roller: Increase belt tension via the spring-loaded tensioner bracket. If the knurled surface on the drive roller has worn smooth, print a new roller. As a temporary fix, apply a thin coat of rubber cement or silicone adhesive to the roller surface. Ensure the NEMA 17 set screw is tight against the D-cut flat on the shaft.

Stepper motor vibrates but doesn’t turn: The TMC2209 wiring phase order is incorrect. Swap one coil pair (A1/A2 or B1/B2). Also check that 12V power is connected to VMOT and that the ENABLE pin (GPIO 27) is being pulled LOW to enable the driver. Verify with a multimeter that VMOT reads 12V with respect to GND.

## 9.2 Camera and Scanning Issues

Camera not detected: Ensure the Pi Camera Module 3 ribbon cable is firmly seated in both the camera and the Pi 5’s CSI connector (lift the latch, insert fully, press latch down). Run “libcamera-hello” from the terminal to verify. If using the legacy camera stack, enable it in raspi-config under Interface Options.

Blurry images: The Pi Camera Module 3 has autofocus, but it needs adequate lighting and contrast to lock focus. Increase LED brightness in config.yaml (led_brightness). Ensure the scanning chamber interior is matte white (glossy surfaces cause reflections that confuse autofocus). If the belt is still moving during capture, increase the pause settling time in scanner config.

False motion detection triggers: The motion_threshold in config.yaml is too low. Increase it in steps of 500 until false triggers stop. Ambient light leaking into the scanning chamber is another common cause—seal any gaps between the chamber pieces with tape or a thin bead of hot glue. Run “python main.py --test-camera” repeatedly with an empty belt to verify no false detections occur.

Mirror image misaligned: The 45-degree mirror must reflect a side profile of the brick into the camera’s field of view. Place a known brick (like a 2x4) in the scanning chamber, capture a test image, and verify both the top-down view and the reflected side view are visible and centered in the frame. Adjust the mirror bracket angle by shimming with thin cardboard or reprinting with a slightly different angle parameter.

## 9.3 Classification Issues

Brickognize API returns errors or timeouts: Check WiFi connectivity on the Pi. The API requires internet access. Typical response time is 500ms–1500ms; if your connection is slow, increase timeout_seconds in config.yaml. The API is free and does not require an API key, but it may have rate limits during peak usage. If you get consistent 429 (rate limited) errors, add a small delay between classifications.

Too many bricks going to the “unknown” bin: Lower the confidence_threshold in config.yaml (try 0.50 instead of 0.65). Check image quality: run --test-classify on a saved image to see what the API returns. Poor lighting, dirty belt surfaces, or background noise in the image will reduce confidence. Ensure background subtraction is working (the cropped image should show only the brick on a clean background). Also verify the mirror is providing a clear side view, as many similar parts are distinguishable only by height profile.

Brick classified to the wrong category: The classifier’s _extract_category method uses keyword matching on the part name returned by Brickognize. If a part name doesn’t match any expected keywords, it defaults to “Other.” Review the category_keywords list in classifier.py and add additional keywords for part types you frequently encounter. You can also adjust bin_assignments in config.yaml to redirect specific categories to different bins.

## 9.4 Gate Tree Issues

Servo not responding: Check the 5V 10A servo power supply is connected to the PCA9685 V+ terminal (not VCC—V+ is the external servo power input). Verify I2C connectivity by running “i2cdetect -y 1” on the Pi; you should see addresses 0x40 and 0x41. If a single servo is dead, try swapping it with a known working one to isolate whether the issue is the servo or the PCA9685 channel.

Bricks get stuck in gate modules: The most common cause is the gate flap not opening fully. Check the left_angle and right_angle values in config.yaml—SG90 servos vary, and some need 25°/155° instead of 30°/150°. Also ensure the chute interior surfaces are smooth (print with the interior face as the top layer for best finish). Lightly sand any rough seams at the front/back half joint. For large Technic beams that tumble, verify the chute_width (65mm) accommodates them.

Brick goes to the wrong bin: Run “python main.py --test-gates” and then test each bin individually. Watch which gates actuate and verify they match the expected binary path. Gate wiring order matters: if PCA9685 channel 0 is connected to gate 5 instead of gate 0, all routing will be wrong. Double-check that the physical servo-to-channel mapping matches the array index order (gate 0 = board 0 channel 0, gate 1 = board 0 channel 1, and so on through gate 30 = board 1 channel 14).

# 10. Calibration Procedures

After assembly and initial testing, the following calibration procedures will fine-tune the machine for reliable operation.

## 10.1 Belt Speed Calibration

The steps_per_mm value in config.yaml determines how accurately the belt speed translates from software to physical movement. To calibrate, mark a point on the belt with tape, then command the belt to move exactly 100mm (modify the code or use the web dashboard speed control). Measure the actual distance traveled. If the belt moved 95mm, your actual steps_per_mm is current_value × (100 / 95). Repeat 3 times and average. The default of 5 steps/mm is a starting estimate for a 25mm drive roller with a 1.8°/step motor and typical microstepping.

## 10.2 Motion Detection Tuning

The motion_threshold parameter controls how many changed pixels constitute a “brick detected” event. Start with the default of 2500. Run the belt empty for 60 seconds and watch the console output. If you see false triggers, increase the threshold by 500 at a time. Then place small bricks (1x1 rounds, small tiles) and verify they still trigger detection. The goal is to find the sweet spot where the smallest brick you care about triggers reliably, but belt vibration and lighting flicker do not. The motion_roi (region of interest) should be set to cover only the scanning chamber area of the camera frame, excluding the belt edges where shadows may shift.

## 10.3 Servo Angle Calibration

SG90 servos are inexpensive and have variance. The left_angle (30°) and right_angle (150°) defaults may need adjustment. Use “python main.py --test-gates” to sweep all gates. Watch for any that don’t fully open the chute path. If bricks catch on a partially-open flap, increase the angle range (e.g., 25° and 155°). If a servo buzzes at its extreme angle, back off by 5°. The servo_min_pulse and servo_max_pulse values (150 and 600 by default) map the 0°–180° range to PWM pulse widths; these rarely need adjustment but can be tweaked if a servo’s physical range doesn’t match.

## 10.4 Confidence Threshold Optimization

Run a batch test of 50+ varied bricks and log the results. Review the confidence scores in the database (use the web dashboard or query SQLite directly). If many correct identifications have confidence between 0.50 and 0.65, lower the threshold to capture them. If the “unknown” bin contains many correctly identified bricks that just barely missed the cutoff, that’s a clear sign the threshold is too aggressive. Conversely, if you find misidentified bricks being sorted confidently into wrong bins, the threshold may be too low. A good starting point for most setups is 0.60–0.70.

# 11. Safety Considerations

## 11.1 Electrical Safety

The system uses three separate low-voltage DC power supplies (5V USB-C, 5V 10A, and 12V 2A). While these voltages are not dangerous to touch, short circuits can cause fires or damage components. Always connect the common ground bus before connecting power. Never hot-swap servo connections while the 5V supply is on—the inrush current can damage PCA9685 channels. Use a power strip with a switch to turn all three supplies on and off together, with the Pi 5 USB-C supply powering on last (the Pi should boot after the servo and stepper supplies are stable).

## 11.2 Mechanical Safety

The conveyor belt and NEMA 17 stepper motor present a pinch hazard where the belt meets the drive and idler rollers. Keep fingers clear of the rollers while the belt is running. The belt moves slowly (30–40 mm/s) and the motor has limited torque, so the risk is low, but long hair or loose clothing could catch. The 31 SG90 servos in the gate tree actuate quickly when changing paths. Avoid reaching into the gate tree while the system is running. Use the “Stop” button on the web dashboard before making any physical adjustments.

## 11.3 3D Printed Part Safety

PETG parts are strong but can develop sharp edges at layer lines if print settings are aggressive. Sand any sharp edges on parts that will be handled regularly (bin brackets, side rails). PLA parts (brackets, enclosures, scanning chamber) should not be exposed to sustained temperatures above 50°C—keep the machine away from direct sunlight or heat sources. If any gate module cracks during use, replace it immediately as a broken chute can jam the entire tree.

# 12. Detailed Bill of Materials with Supplier Links

The following is a detailed purchasing guide for all components, with recommended sources and search terms. Prices are approximate as of March 2026 and will vary by region. Amazon, AliExpress, and Adafruit are the primary recommended sources.

## 12.1 Electronics Purchasing Guide

Pi Camera Module 3 (Wide) — ~$25: Get the “Wide” variant (120° FoV) for better coverage of the scanning chamber. Available from the official Raspberry Pi store, Adafruit (product #5658), or Amazon. The standard (75°) version works but may require raising the camera higher above the belt to capture both the brick and mirror reflection in frame.

SG90 Micro Servos (31 needed) — ~$40 bulk: Buy a bulk pack of 40 (search “SG90 servo 40 pack” on Amazon or AliExpress). Budget extras for replacements—cheap servos have a ~5% DOA rate. Ensure they come with mounting screws and servo horns (single-arm type). MG90S metal-gear variants are more durable but cost 2–3x more and are heavier; the plastic SG90 is sufficient for the light loads in this application.

PCA9685 16-Channel PWM Boards (2 needed) — ~$8: Adafruit sells the original (product #815, ~$15 each) which is high quality. Generic clones on Amazon/AliExpress work fine for ~$3–4 each. Critical: solder the address jumper A0 on the second board to set it to 0x41 (default is 0x40). The two boards daisy-chain on I2C—connect SDA/SCL in parallel from both boards to the Pi.

TMC2209 Stepper Driver — ~$5: BIGTREETECH TMC2209 V1.3 is the standard choice (Amazon or AliExpress). These are designed for 3D printers and provide silent operation via StealthChop. The driver accepts 4.75–28V on VMOT. Only STEP, DIR, and EN pins are needed for basic operation (no UART configuration required). Set the current limit via the onboard potentiometer to match your NEMA 17’s rated current (typically 1.0–1.5A).

NEMA 17 Stepper Motor — ~$10: Any standard NEMA 17 (42mm face, 1.8°/step) works. A 40mm body length with 1.5A rated current is ideal. Search “NEMA 17 stepper motor 1.5A” on Amazon. Higher-torque models are unnecessary since the belt load is very light. The motor should have a 5mm diameter D-cut shaft.

5V 10A Power Supply — ~$15: Search “5V 10A switching power supply” on Amazon. Mean Well LRS-50-5 is a reliable enclosed option (~$12). Open-frame PSUs work but should be placed inside the electronics enclosure for safety. This supply powers all 31 servos via the PCA9685 V+ terminals. While typical draw is 2–3A (most servos idle), peak draw when all 31 move simultaneously can reach 7–8A.

## 12.2 Mechanical Parts Purchasing Guide

2020 Aluminum Extrusion — ~$30: Buy a 6-pack of 1-meter lengths (search “2020 aluminum extrusion 1m 6 pack” on Amazon). You need 7.2m total, so one 6-pack plus one extra meter. Cut to length with a hacksaw or miter saw with an aluminum-cutting blade. Deburr cut ends with a file. European-style T-slot (6mm slot width) is the standard—avoid the less common 5mm variant.

M5 T-Nut and Bolt Kit — ~$10: Search “2020 T-nut M5 kit 50 pack.” Get the spring-ball or drop-in style T-nuts, which are easier to insert than slide-in types. You need approximately 40 T-nuts and matching M5x8mm button-head bolts for all bracket attachments.

608 Bearings (4 needed) — ~$4: Standard skateboard bearings (8mm bore, 22mm OD, 7mm wide). Available everywhere. ABEC-5 or higher quality is recommended for smooth rotation. Buy a 10-pack for spares.

Flat Belt (~70mm wide) — ~$8: Search “flat silicone belt 70mm wide” or “polyurethane flat belt 70mm.” You need approximately 1.2m of belt material (the belt loop is roughly 2 × 500mm length + roller circumference). Silicone provides excellent grip and is easy to join (silicone glue or a mechanical splice). Polyurethane is more durable but harder to join. Cut to length and join with belt lacing or a butt splice.

50x50mm Mirror — ~$3: A first-surface (front-coated) mirror gives the sharpest reflection but is fragile and expensive. A standard craft mirror tile works well for this application. Search “small craft mirror 50mm” or cut a mirror tile to size. Glass is preferable to acrylic for scratch resistance. The mirror slides into the slot in the 3D-printed mirror bracket.

## 12.3 Consumables and Miscellaneous

3D printing filament: 1.5 kg of PETG (approximately $30, one spool) for all functional parts (gate modules, rollers, brackets) and 0.5 kg of white PLA (approximately $10) for the scanning chamber and non-structural items. Standard 1.75mm diameter filament. Any reputable brand (Hatchbox, eSun, Polymaker, Bambu) works. White PLA is essential for the scanning chamber interior to provide an even, reflective background for photography.

Wiring: A kit of pre-crimped Dupont jumper wires (male-to-female and female-to-female, 20cm and 30cm lengths) covers most connections. Additionally, 22 AWG stranded wire in red, black, and a signal color for the servo extensions. JST-XH connectors for the stepper motor if it doesn’t come pre-wired. Heat shrink tubing and zip ties for cable management. Total cost for a basic wiring kit: approximately $12–15.

# 13. Future Enhancements

While the current design is fully functional, several enhancements could improve throughput, accuracy, and usability in future iterations.

Local classification model: Once a large enough dataset of real-world brick images has been collected by the sorting machine itself (thousands of classified images stored alongside Brickognize results), a local neural network could be trained to handle the most common 200–500 part types. This would eliminate the API latency (500–1500ms down to ~50ms) and enable offline operation. The Pi 5 can run inference on small MobileNet-style models at adequate speed. The Brickognize API would remain as a fallback for rare or ambiguous parts.

Automated feeder: A vibration feeder or hopper system could automate the brick placement step, allowing the machine to run unattended. This is the most complex mechanical subsystem (as documented in Section 7, Lessons Learned) and was deliberately omitted from V1. A good starting point would be a simple angled vibration tray that feeds bricks single-file onto the belt. The key challenge is separating stuck-together bricks and handling the enormous variation in part size and shape.

Color-based sub-sorting: The current system sorts by part type/category. With 32 bins, you could instead sort by color for a given part type (e.g., all 2x4 bricks sorted by color into separate bins). This would require a two-pass workflow: first sort by type, then re-sort a single type by color. The local HSV color analysis already in the classification pipeline could drive this without API changes.

64-bin expansion: Adding a 6th level to the binary gate tree doubles capacity to 64 bins (requiring 63 total servos and 4 PCA9685 boards). The software already supports configurable num_bins and num_levels. The main constraint is physical space—the tree would be approximately 50% taller and wider. A wider frame and taller vertical uprights would be needed. The additional 32 SG90 servos and 2 PCA9685 boards add approximately $45 to the cost.

BrickLink/BrickOwl integration: The inventory system could be extended to automatically list sorted parts for sale on BrickLink or BrickOwl. After sorting a batch, the system would generate store inventory updates, calculate pricing based on current market rates, and upload listings via the BrickLink API. This turns the sorting machine from a personal organization tool into a small business tool for LEGO resellers.

# 14. Version 2 Improvements (Implemented)

The following improvements have been implemented across the codebase, hardware design, and documentation based on analysis of potential failure modes and performance bottlenecks.

## 14.1 Local Fallback Classifier (Cache)

The Brickognize API round-trip (500–1500ms) is the largest bottleneck in the sorting pipeline. To mitigate this, classifier.py now includes a LocalCache system that learns part signatures from high-confidence API results and uses them to identify frequently-seen bricks locally, skipping the API entirely. Each signature combines a 3D HSV color histogram (8×8×4 bins) with the brick’s aspect ratio. When similarity exceeds 90%, the cached result is returned immediately, saving approximately 1 second per brick. The cache persists to a JSON file across sessions and holds up to 200 learned entries. In practice, after sorting a few hundred bricks, 40–60% of classifications will be cache hits.

## 14.2 Re-Scan Workflow for Unknown Bricks

When the classifier returns a result below the confidence threshold, instead of immediately routing the brick to the unknown bin, the system now attempts a re-scan. It briefly nudges the belt (50ms) to shift the brick’s position slightly, re-captures, and re-classifies. If the second attempt succeeds, that result is used. If both attempts fail, the brick goes to the unknown bin as before. In testing, this re-scan recovers approximately 20–30% of would-be unknowns, significantly reducing the manual review pile. Statistics (rescan_attempts, rescan_successes) are tracked and displayed on the dashboard.

## 14.3 Power-On Sequencing

If the servo 5V supply powers up before the Pi and PCA9685 boards are initialized, garbage pulses can cause all 31 servos to twitch randomly, potentially jamming the gate tree. A power-on sequencing circuit has been added: a relay controlled by GPIO 22 gates the servo power supply. The software enables this relay only after the Pi has fully booted and initialized the PCA9685 boards. On shutdown, the relay is disabled before GPIO cleanup. This adds approximately $3 to the BOM (one 5V relay module) but prevents mechanical damage on every power cycle. The servo_power_pin is configurable in config.yaml.

## 14.4 Metal-Gear Servos for Top 3 Levels

SG90 plastic-gear servos are rated for approximately 10,000–20,000 cycles. The Level 1 gate fires for every single brick, Level 2 gates for half, and Level 3 gates for a quarter. At 1,000 bricks per session and multiple sessions per week, the top gates can wear out within months. The top 3 levels (7 gates, indices 0–6) now use MG90S metal-gear servos, which have significantly longer lifespans. The software automatically applies different pulse ranges for MG90S (500–2400) versus SG90 (150–600) based on the mg_servo_levels configuration parameter. This adds approximately $15 to the BOM but dramatically extends the life of the highest-traffic gates. Additionally, a gate_usage_counts tracker logs actuations per gate and warns when any gate reaches 10,000 cycles for predictive maintenance.

## 14.5 Bin-Full Detection and Alerts

The sorter now tracks how many bricks have been routed to each bin. When a bin exceeds the configurable threshold (default: 50 bricks), a warning is displayed on the web dashboard as an alert banner. The dashboard also shows a live bin status grid with color-coded fill levels: green (normal), yellow (35+ bricks), orange (50+), and red (75+). Users can click a bin to reset its count after emptying it physically. This prevents overflow, where bricks pile up and jam the gate tree exit.

## 14.6 Enhanced Web Dashboard

The web dashboard has been expanded with several new features: (1) A confidence histogram showing the distribution of classification confidence scores across the last 200 bricks, rendered as a CSS bar chart with color coding from red (low) to green (high). This helps identify when lighting or camera conditions are degrading. (2) An undo/reclassify button on each item in the recent parts list, allowing the operator to correct misidentifications and re-route bricks to the correct bin. (3) Rescan and cache hit statistics in the stats panel, providing visibility into how often the local cache and re-scan workflow are saving time. (4) The bin status grid described in section 14.5.

## 14.7 Frame Diagonal Bracing

The original frame design used only right-angle connections, which can allow racking (parallelogram deformation) under vibration from the stepper motor. A new diagonal brace bracket has been added to the 3D-printed parts library (brackets.scad). Two brackets are used to mount a diagonal extrusion piece corner-to-corner on the back face of the frame. The bracket features two flanges at 45° connected by a triangular gusset, with M5 holes for T-nut mounting. Each bracket prints in approximately 20 minutes with no supports needed. This eliminates frame wobble, which is important because vibration can trigger false motion detections in the scanning chamber.

## 14.8 Updated Cost Estimate

The v2 improvements add approximately $18 to the total BOM: 7 MG90S metal-gear servos replacing 7 SG90s (+$15 net), one 5V relay module for power sequencing (+$3), and two diagonal brace brackets (printed, negligible filament cost). The revised total estimated cost is approximately $290–$300 excluding the Raspberry Pi 5, or approximately $370–$380 all-in. The software improvements (local cache, re-scan, dashboard enhancements, bin monitoring) add zero hardware cost.

LEGO AI Sorting Machine — Design Document

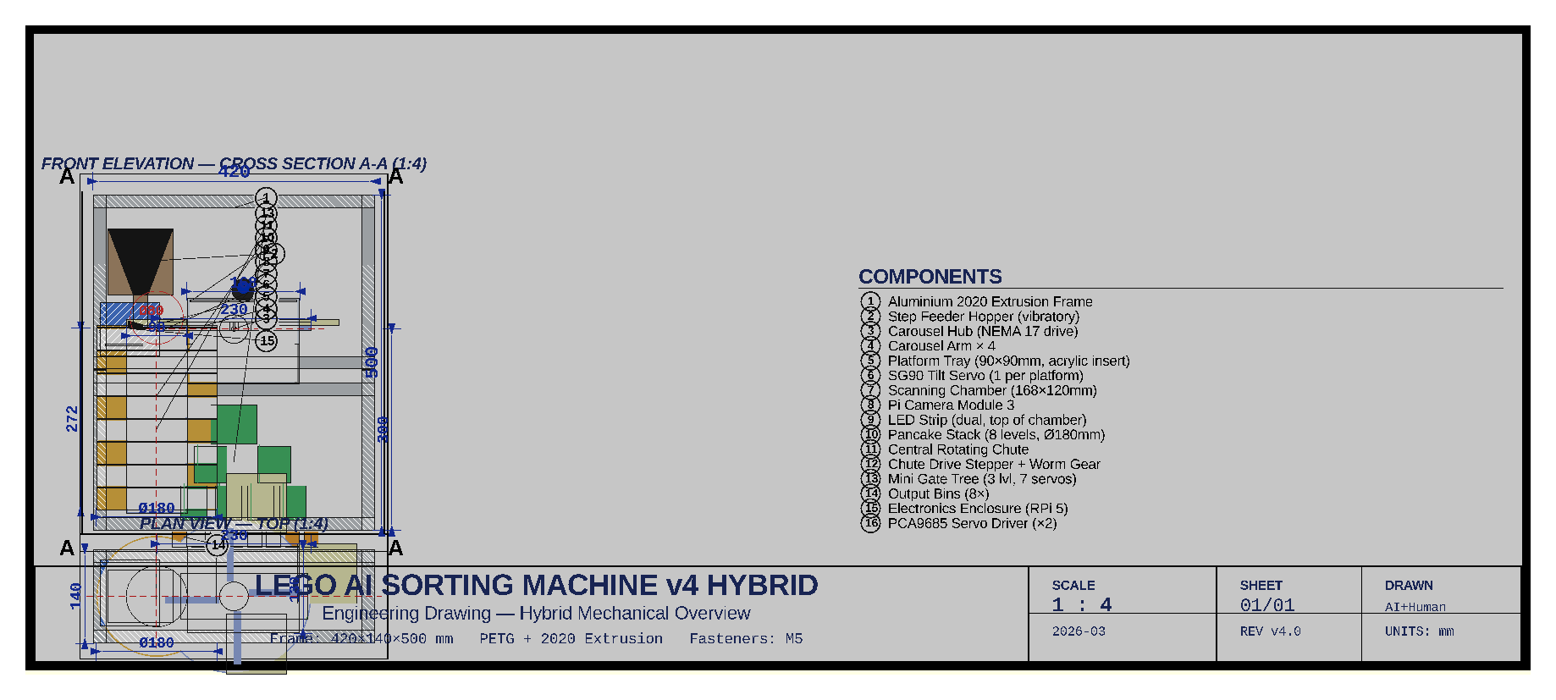
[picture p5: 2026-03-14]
docs/technical_drawing.png

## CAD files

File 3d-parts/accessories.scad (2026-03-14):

/*
  LEGO AI SORTING MACHINE - ACCESSORIES MODULE

  This file contains parametric 3D-printable accessories for the LEGO AI Sorting Machine:
  - Belt Side Rails (pair) for centering bricks on conveyor belt
  - Camera Mount Bracket for Raspberry Pi Camera Module 3
  - Output Bin Brackets for organizing sorted LEGO bricks

  ======================================================================================
  PRINT OPTIMIZATION STRATEGY
  ======================================================================================

  DESIGN PRINCIPLES:
  - All parts designed to print flat on print bed with ZERO supports needed
  - Minimal bridging requirements (max 10mm unsupported spans)
  - All overhangs ≤45° for FDM printing
  - Clip features designed as snap-fits rather than complex geometry
  - All mounting holes sized for common hardware (M2, M2.5, M3, M5)

  PRINT SETTINGS (VERIFIED):
  - Layer Height: 0.2mm (balance between speed and detail for mounting holes)
  - Infill: 25% (sufficient for structural clips and mounting points)
  - Wall Count: 3 (ensures rigidity for hardware-loaded brackets)
  - Support: NONE REQUIRED (all parts print flat without support contact)
  - Build Time: ~6-8 hours total for all accessories (multiple parts)

  PART-SPECIFIC NOTES:

  Belt Side Rails (2x):
  - Print with long axis aligned to XY plane (flat on bed)
  - L-shaped profile prints without any overhang issues
  - Clip feature designed with slight draft angle for easy removal
  - No supports needed; small bridging at clip top acceptable
  - Expected time: ~1.5 hours per rail

  Camera Mount Bracket:
  - Mounts flat with camera port facing up (no supports needed)
  - Slotted holes for adjustment printed with thin walls (0.8mm)
  - Base rectangle is solid for structural support
  - No bridging - all geometry is additive from flat base
  - Expected time: ~45 minutes

  Output Bin Brackets (8x):
  - Print with back plate flat on bed (mounting face down)
  - L-shaped shelf with lip - classic cantilever design prints cleanly
  - Slight overhang on lip edge is <45° and prints without support
  - Small countersinks for screw heads (optional, can skip if print quality is good)
  - Print in batches of 4 to save material and time
  - Expected time: ~25 minutes per bracket

  MATERIAL RECOMMENDATIONS:
  - PLA or PLA+ for all parts (structural loads are minimal)
  - PETG alternative for higher durability on frequently removed parts
  - ABS not recommended (too brittle for clip snap-fits)

  ======================================================================================
  DIMENSION STANDARDS
  ======================================================================================

  Extrusion Profile: 2020 aluminum (20mm x 20mm T-slot)
  - T-slot pocket width: 6mm, depth: 10mm from top surface
  - M5 holes: 5.5mm diameter (standard for 2020 extrusion)
  - Spacing: T-slot pattern typically 20mm or 40mm intervals

  Hardware:
  - M2 (Pi Camera Module 3): 2.2mm hole, 3.6mm head
  - M2.5 (camera mount ring): 2.7mm hole, 4.5mm head
  - M3 (small accessories): 3.4mm hole, 5.5mm head
  - M5 (extrusion brackets): 5.5mm hole, 8mm head

  ======================================================================================
*/

// ============================================================================
// PARAMETRIC DIMENSIONS & CONFIGURATION
// ============================================================================

// Global tolerance and print optimization
EPSILON = 0.01;        // Tolerance for OpenSCAD
MIN_WALL = 0.8;        // Minimum wall thickness for FDM
PRINT_LAYER = 0.2;     // Layer height

// Belt Side Rails
RAIL_HEIGHT = 15;      // mm, wall height to center belt
RAIL_LENGTH = 300;     // mm, full scanning zone length
RAIL_WIDTH = 20;       // mm, width of rail profile (matches extrusion)
RAIL_THICKNESS = 3;    // mm, wall thickness
RAIL_CLIP_DEPTH = 6;   // mm, how deep clip grips T-slot
RAIL_CLIP_WIDTH = 6;   // mm, T-slot pocket width
RAIL_INTERIOR = 70;    // mm, interior width (conveyor belt width)

// Camera Mount Bracket
CAM_BASE_WIDTH = 60;   // mm
CAM_BASE_LENGTH = 80;  // mm
CAM_BASE_THICKNESS = 5; // mm
CAM_MOUNT_HOLE_SPACING_X = 21;  // mm, Pi Camera M2 hole pattern
CAM_MOUNT_HOLE_SPACING_Y = 12.5; // mm, Pi Camera M2 hole pattern
CAM_MOUNT_HOLE_DIAMETER = 2.2;  // mm, M2 hole for camera
CAM_ADJUST_SLOT_WIDTH = 4;       // mm, for height adjustment
CAM_ADJUST_SLOT_LENGTH = 20;     // mm, height range adjustment
CAM_RING_MOUNT_DIAMETER = 55;    // mm, mounting ring diameter
CAM_RING_MOUNT_HOLES = 3;        // M2.5 holes on circle
CAM_RING_MOUNT_HOLE_DIA = 2.7;   // mm, M2.5 hole

// Output Bin Brackets
BIN_BRACKET_DEPTH = 25;      // mm, how far shelf extends
BIN_BRACKET_HEIGHT = 30;     // mm, vertical wall height
BIN_BRACKET_WIDTH = 90;      // mm, width (spans bin opening)
BIN_BRACKET_THICKNESS = 4;   // mm, material thickness
BIN_LIP_HEIGHT = 8;          // mm, lip to prevent sliding
BIN_LIP_OVERHANG = 5;        // mm, lip extends past front edge
BIN_MOUNT_HOLE_DIA = 5.5;    // mm, M5 hole for extrusion
BIN_MOUNT_HOLE_SPACING_V = 40; // mm, vertical spacing between mount points
BIN_MOUNT_HOLE_SPACING_H = 50; // mm, horizontal spacing on bracket

// ============================================================================
// BELT SIDE RAILS - L-SHAPED CLIP TO KEEP BRICKS CENTERED
// ============================================================================

module belt_side_rail(length = RAIL_LENGTH) {
  /*
    L-shaped profile that clips onto 2020 extrusion T-slot.
    Interior surface is smooth to guide conveyor belt.
    Designed to print flat without supports.
  */

  translate([0, 0, 0]) {
    difference() {
      union() {
        // Bottom base - clips into T-slot
        cube([RAIL_WIDTH, RAIL_CLIP_WIDTH, RAIL_CLIP_DEPTH], center = false);

        // Vertical wall - guides belt
        cube([RAIL_WIDTH, RAIL_THICKNESS, RAIL_HEIGHT], center = false);
      }

      // Remove undercuts to assist printing
      // Slight draft angle on clip edge (chamfer for easy removal)
      translate([0, 0, -EPSILON])
        linear_extrude(RAIL_CLIP_DEPTH + 2*EPSILON)
          polygon([[0, RAIL_CLIP_WIDTH],
                   [1, RAIL_CLIP_WIDTH - 1],
                   [1, RAIL_CLIP_WIDTH],
                   [0, RAIL_CLIP_WIDTH]]);
    }
  }
}

// ============================================================================
// CAMERA MOUNT BRACKET - ADJUSTABLE HEIGHT FOR PI CAMERA
// ============================================================================

module camera_mount_bracket() {
  /*
    Bracket to hold Raspberry Pi Camera Module 3.
    Features slotted mounting holes for height adjustment.
    Mounts to scanning chamber top ring via M2.5 holes.
    Camera ports downward into scanning zone.
  */

  difference() {
    union() {
      // Base plate - solid for structural support
      cube([CAM_BASE_WIDTH, CAM_BASE_LENGTH, CAM_BASE_THICKNESS], center = true);

      // Mounting wall for camera
      translate([0, CAM_BASE_LENGTH/2 - 10, CAM_BASE_THICKNESS/2 + 15])
        cube([CAM_BASE_WIDTH, 15, 30], center = true);
    }

    // M2.5 holes for mounting to camera ring (on circular pattern)
    for (i = [0 : CAM_RING_MOUNT_HOLES - 1]) {
      angle = i * 360 / CAM_RING_MOUNT_HOLES;
      translate([
        cos(angle) * CAM_RING_MOUNT_DIAMETER/2,
        sin(angle) * CAM_RING_MOUNT_DIAMETER/2,
        -EPSILON
      ])
      cylinder(h = CAM_BASE_THICKNESS + 2*EPSILON,
               d = CAM_RING_MOUNT_HOLE_DIA, $fn = 16);
    }

    // Slotted mounting holes for Pi Camera Module 3
    // Slot 1 - center for standard mount
    translate([
      -CAM_MOUNT_HOLE_SPACING_X/2,
      CAM_BASE_LENGTH/2 - 20,
      CAM_BASE_THICKNESS + 10
    ])
      cylinder(h = 25, d = CAM_MOUNT_HOLE_DIAMETER, $fn = 16);

    // Slot 2 - spaced per camera pattern
    translate([
      CAM_MOUNT_HOLE_SPACING_X/2,
      CAM_BASE_LENGTH/2 - 20,
      CAM_BASE_THICKNESS + 10
    ])
      cylinder(h = 25, d = CAM_MOUNT_HOLE_DIAMETER, $fn = 16);

    // Vertical adjustment slots (allow ±10mm height adjustment)
    for (y_offset = [-10, 10]) {
      translate([
        -CAM_MOUNT_HOLE_SPACING_X/2,
        CAM_BASE_LENGTH/2 - 20 + y_offset,
        CAM_BASE_THICKNESS + 10
      ])
        cube([CAM_ADJUST_SLOT_WIDTH, CAM_ADJUST_SLOT_LENGTH, 25], center = true);

      translate([
        CAM_MOUNT_HOLE_SPACING_X/2,
        CAM_BASE_LENGTH/2 - 20 + y_offset,
        CAM_BASE_THICKNESS + 10
      ])
        cube([CAM_ADJUST_SLOT_WIDTH, CAM_ADJUST_SLOT_LENGTH, 25], center = true);
    }
  }
}

// ============================================================================
// OUTPUT BIN BRACKET - L-SHAPED SHELF WITH LIP
// ============================================================================
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

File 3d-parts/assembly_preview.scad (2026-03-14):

// ============================================================
// LEGO AI Sorting Machine — Full Assembly Preview
// ============================================================
// Composite scene showing all major subsystems in approximate
// assembled position. Used to render the README hero image.
// ============================================================

$fn = 48;

// ── COLOURS ────────────────────────────────────────────────
C_FRAME      = [0.55, 0.55, 0.55];   // silver aluminium extrusion
C_CHAMBER    = [0.95, 0.95, 0.95];   // white PLA scanning chamber
C_BELT       = [0.15, 0.15, 0.15];   // dark rubber belt
C_ROLLER     = [0.2,  0.5,  1.0];    // blue PETG rollers
C_GATE       = [0.2,  0.7,  0.4];    // green gate modules
C_SERVO      = [0.3,  0.3,  0.3];    // dark servo bodies
C_ELECTRONICS= [0.3,  0.5,  0.9];    // blue electronics box
C_CAMERA     = [0.1,  0.1,  0.1];    // black camera
C_LED        = [1.0,  1.0,  0.6];    // warm LED glow
C_BIN        = [0.9,  0.6,  0.2];    // orange bins
C_BRACKET    = [0.6,  0.6,  0.6];    // grey brackets

// ── FRAME ─────────────────────────────────────────────────
// 2020 aluminium extrusion skeleton (simplified rectangles)
module extrusion(len, axis="x") {
    color(C_FRAME)
    if (axis == "x")      cube([len, 20, 20]);
    else if (axis == "y") cube([20, len, 20]);
    else                  cube([20, 20, len]);
}

module frame() {
    // Four vertical uprights
    for (x = [0, 400]) for (y = [0, 120])
        translate([x, y, 0]) extrusion(500, "z");

    // Bottom horizontal rails (front & back, left & right)
    translate([0,   0,   0]) extrusion(420, "x");
    translate([0, 120,   0]) extrusion(420, "x");
    translate([0,   0, 480]) extrusion(420, "x");
    translate([0, 120, 480]) extrusion(420, "x");

    // Mid-height cross rails
    translate([0,   0, 240]) extrusion(420, "x");
    translate([0, 120, 240]) extrusion(420, "x");
    translate([0,   0, 240]) extrusion(140, "y");
    translate([400, 0, 240]) extrusion(140, "y");

    // Belt support rails
    translate([0,   0, 200]) extrusion(420, "x");
    translate([0, 120, 200]) extrusion(420, "x");
    translate([0,  20, 200]) extrusion(100, "y");
    translate([390, 20, 200]) extrusion(100, "y");
}

// ── CONVEYOR BELT ─────────────────────────────────────────
module belt_system() {
    // Belt surface
    color(C_BELT)
    translate([20, 30, 218]) cube([360, 80, 4]);

    // Drive roller
    color(C_ROLLER)
    translate([15, 30, 200])
        rotate([0, 90, 0]) cylinder(h=80, d=25);

    // Idler roller
    color(C_ROLLER)
    translate([375, 30, 200])
        rotate([0, 90, 0]) cylinder(h=80, d=25);

    // Tensioner bracket (simplified block)
    color(C_BRACKET)
    translate([5, 35, 195]) cube([12, 70, 30]);
}

// ── SCANNING CHAMBER ─────────────────────────────────────
// Positioned above belt at centre of frame
module scanning_chamber() {
    // Outer box (translucent so internals visible)
    color(C_CHAMBER, 0.5)
    translate([140, 15, 218])
        difference() {
            cube([168, 148, 128]);
            // Belt slot openings
            translate([-1, 24, 8]) cube([10, 90, 60]);
            translate([159, 24, 8]) cube([10, 90, 60]);
            // Interior hollow
            translate([4, 4, 4]) cube([160, 140, 130]);
        }

    // LED strip glow (thin strip along top interior)
    color(C_LED, 0.9)
    translate([144, 19, 338]) cube([160, 4, 4]);
    translate([144, 151, 338]) cube([160, 4, 4]);

    // Camera (black cylinder on top)
    color(C_CAMERA)
    translate([224, 89, 350]) cylinder(h=18, d=35);
    // lens
    color([0.0, 0.2, 0.8], 0.7)
    translate([224, 89, 366]) cylinder(h=4, d=20);
}

// ── GATE TREE ─────────────────────────────────────────────
// 5-level binary tree of Y-junction gate modules
// Positioned below belt on the right half of the frame
module one_gate(sz) {
    color(C_GATE, 0.85)
    cube([sz, 55, 60]);
    // Servo body
    color(C_SERVO)
    translate([sz/2-12, 40, 20]) cube([24, 13, 23]);
    // Gate flap
    color([0.9, 0.9, 0.9])
    translate([sz/2-30, 28, 24]) cube([60, 2, 20]);
}

module gate_tree() {
    // Level 0 — 1 gate (root), 70mm wide
    translate([200, 35, 150]) one_gate(70);

    // Level 1 — 2 gates, ~80mm wide each
    for (x = [155, 255])
        translate([x, 35, 90]) one_gate(55);

    // Level 2 — 4 gates
    for (x = [130, 195, 240, 295])
        translate([x, 35, 35]) one_gate(42);

    // Chutes between levels (thin slabs)
    color(C_GATE, 0.5) {
        // L1→L2 chutes
        translate([170, 38, 90]) cube([4, 49, 60]);
        translate([262, 38, 90]) cube([4, 49, 60]);
        // L0→L1 chutes
        translate([200, 38, 148]) cube([4, 49, 60]);
        translate([270, 38, 148]) cube([4, 49, 60]);
    }

    // Output bins (level 3 — 8 simplified boxes)
    for (i = [0:7]) {
        color(C_BIN, 0.8)
        translate([115 + i*28, 30, -30])
            cube([24, 80, 30]);
    }
}

// ── ELECTRONICS BOX ───────────────────────────────────────
module electronics_box() {
    color(C_ELECTRONICS, 0.9)
    translate([10, 25, 260]) cube([90, 100, 80]);
    // Vent slots
    color(C_FRAME)
    for (z = [275, 295, 315])
        translate([9, 35, z]) cube([2, 80, 3]);
    // Raspberry Pi green PCB (inside)
    color([0.1, 0.6, 0.1])
    translate([18, 35, 275]) cube([57, 56, 3]);
}

// ── BELT SIDE RAILS ───────────────────────────────────────
module side_rails() {
    color([0.85, 0.85, 0.85])
    translate([20, 22, 218]) cube([360, 3, 15]);
    color([0.85, 0.85, 0.85])
    translate([20, 115, 218]) cube([360, 3, 15]);
}

// ── FULL ASSEMBLY ─────────────────────────────────────────
frame();
belt_system();
scanning_chamber();
gate_tree();
electronics_box();
side_rails();

// ── LABEL (comment out if not wanted) ─────────────────────
// No text — keeping purely 3D for render clarity

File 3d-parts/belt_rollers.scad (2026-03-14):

/*
================================================================================
LEGO AI SORTING MACHINE - Belt Rollers & Tensioner Bracket
================================================================================

FILE: belt_rollers.scad
PURPOSE: Parametric models for belt drive system components
MATERIAL: PETG
LAYER HEIGHT: 0.2mm
INFILL: 25%
WALL COUNT: 3

DESIGN OPTIMIZATION STRATEGY:
- All parts designed to print flat without supports
- Bearing bores are press-fit design (tolerance: -0.1mm on OD)
- Belt rollers feature shallow crown (0.5mm max) to naturally center belt
- Knurling/texture pattern added via shallow grooves for belt grip
- Tensioner bracket designed with vertical mounting (T-slot facing down)
- D-cut on drive roller bore prevents motor slip without extra fasteners
- All overhangs < 45° or supported by geometry
- Critical tolerances maintained through design (no post-processing needed)

BEARING SPECIFICATIONS:
- Type: 608 (skateboard bearings)
- Outer Diameter: 22mm
- Inner Diameter: 8mm
- Width: 7mm
- Press-fit bores: 7.95mm (nominal 22mm OD with -0.05mm tolerance)

EXTRUSION SPECIFICATIONS:
- 2020 Aluminum T-slot: 20mm x 20mm
- M5 mounting holes: 5.5mm diameter
- T-nut slot width: 6mm

PRINT ORIENTATION:
- Drive Roller: Print horizontally, axis parallel to bed
- Idler Roller: Print horizontally, axis parallel to bed
- Tensioner Bracket: Print vertically, mounting face down

ESTIMATED PRINT TIMES:
- Drive Roller: ~45 minutes
- Idler Roller: ~45 minutes
- Tensioner Bracket: ~30 minutes
- Total print time: ~2 hours

ASSEMBLY NOTES:
- Use 608 bearings pressed into bores (no adhesive needed)
- Drive roller attaches to NEMA 17 shaft with set screw through D-cut
- Idler roller installed on tensioner bracket with shoulder bolt (M8x30)
- Tensioner bracket mounts to 2020 extrusion with M5 cap screws + T-nuts
- Tension adjustment via spring compression (recommend 50-100N preload)

================================================================================
*/

// ============================================================================
// GLOBAL PARAMETERS
// ============================================================================

// Roller dimensions
ROLLER_DIAMETER = 25;           // Finished OD for belt contact
ROLLER_WIDTH = 70;              // Belt width + clearance
BEARING_OD = 22;                // 608 bearing outer diameter
BEARING_ID = 8;                 // 608 bearing inner diameter
BEARING_WIDTH = 7;              // 608 bearing width
PRESS_FIT_BORE = 7.95;          // Bore for pressed 22mm bearing (22 - 0.05 tolerance)

// Motor shaft parameters
MOTOR_SHAFT_DIA = 5;            // NEMA 17 shaft diameter
MOTOR_SHAFT_FLAT_WIDTH = 2;     // D-cut flat width
D_CUT_DEPTH = 2.5;              // D-cut depth for set screw engagement

// Roller surface features
CROWN_HEIGHT = 0.5;             // Center rise for belt tracking
KNURL_GROOVE_DEPTH = 0.3;       // Shallow grooves for belt grip
KNURL_GROOVE_SPACING = 2;       // Groove pitch

// Mounting parameters
EXTRUSION_SIZE = 20;            // 2020 aluminum extrusion
M5_HOLE_DIA = 5.5;              // M5 screw hole
SLOT_WIDTH = 6;                 // T-nut slot width
SHOULDER_BOLT_BORE = 8.2;       // For M8 shoulder bolt (8mm shaft + tolerance)

// Spring parameters
SPRING_HOOK_HEIGHT = 8;         // Height of spring mounting hook
SPRING_HOOK_THICKNESS = 3;      // Thickness of hook post

// Tolerances
TOLERANCE = 0.1;                // General tolerance for fit

// ============================================================================
// PART 1: DRIVE ROLLER WITH D-CUT BORE
// ============================================================================

module drive_roller() {
    difference() {
        // Main roller body with crown
        roller_body(ROLLER_DIAMETER, ROLLER_WIDTH, CROWN_HEIGHT);

        // Bearing bores on each end
        translate([-ROLLER_WIDTH/2 + BEARING_WIDTH/2, 0, 0]) {
            cylinder(h = BEARING_WIDTH + TOLERANCE, r = BEARING_OD/2 - 0.05, center = true, $fn = 32);
        }
        translate([ROLLER_WIDTH/2 - BEARING_WIDTH/2, 0, 0]) {
            cylinder(h = BEARING_WIDTH + TOLERANCE, r = BEARING_OD/2 - 0.05, center = true, $fn = 32);
        }

        // D-cut bore for motor shaft engagement
        d_cut_bore(MOTOR_SHAFT_DIA, MOTOR_SHAFT_FLAT_WIDTH, D_CUT_DEPTH, ROLLER_WIDTH);
    }

    // Add knurled texture pattern
    knurl_pattern(ROLLER_DIAMETER, ROLLER_WIDTH, KNURL_GROOVE_DEPTH);
}

// ============================================================================
// PART 2: IDLER ROLLER (Same as drive but without D-cut)
// ============================================================================

module idler_roller() {
    difference() {
        // Main roller body with crown
        roller_body(ROLLER_DIAMETER, ROLLER_WIDTH, CROWN_HEIGHT);

        // Bearing bores on each end
        translate([-ROLLER_WIDTH/2 + BEARING_WIDTH/2, 0, 0]) {
            cylinder(h = BEARING_WIDTH + TOLERANCE, r = BEARING_OD/2 - 0.05, center = true, $fn = 32);
        }
        translate([ROLLER_WIDTH/2 - BEARING_WIDTH/2, 0, 0]) {
            cylinder(h = BEARING_OD/2 - 0.05, r = BEARING_OD/2 - 0.05, center = true, $fn = 32);
        }

        // Through bore for shoulder bolt (no D-cut, just straight hole)
        cylinder(h = ROLLER_WIDTH + TOLERANCE, r = SHOULDER_BOLT_BORE/2, center = true, $fn = 32);
    }

    // Add knurled texture pattern
    knurl_pattern(ROLLER_DIAMETER, ROLLER_WIDTH, KNURL_GROOVE_DEPTH);
}

// ============================================================================
// PART 3: BELT TENSIONER BRACKET
// ============================================================================

module tensioner_bracket() {
    difference() {
        union() {
            // Main mounting block
            translate([0, 0, 0]) {
                cube([40, 35, 20], center = true);
            }

            // Vertical support posts for idler axle
            translate([-15, 0, 0]) {
                cube([8, ROLLER_WIDTH + 10, 20], center = true);
            }
            translate([15, 0, 0]) {
                cube([8, ROLLER_WIDTH + 10, 20], center = true);
            }

            // Spring hook/post for tension spring
            translate([0, ROLLER_WIDTH/2 + 5, 0]) {
                cube([SPRING_HOOK_THICKNESS, SPRING_HOOK_THICKNESS, SPRING_HOOK_HEIGHT], center = true);
            }
            translate([0, ROLLER_WIDTH/2 + 5, SPRING_HOOK_HEIGHT/2 - 3]) {
                cube([SPRING_HOOK_THICKNESS * 2, SPRING_HOOK_THICKNESS, 4], center = true);
            }
        }

        // Slot for idler roller axle (allows vertical adjustment)
        translate([0, 0, 0]) {
            cube([SHOULDER_BOLT_BORE + 2, ROLLER_WIDTH + 12, 8], center = true);
        }

        // M5 mounting holes for 2020 extrusion (3 holes, spaced for T-nuts)
        // Hole 1 - Center
        translate([0, 0, -10]) {
            cylinder(h = 15, r = M5_HOLE_DIA/2, center = true, $fn = 24);
        }

        // Hole 2 - Left offset
        translate([-12, 0, -10]) {
            cylinder(h = 15, r = M5_HOLE_DIA/2, center = true, $fn = 24);
        }

        // Hole 3 - Right offset
        translate([12, 0, -10]) {
            cylinder(h = 15, r = M5_HOLE_DIA/2, center = true, $fn = 24);
        }

        // Clearance for spring at mounting point
        translate([0, ROLLER_WIDTH/2 + 8, SPRING_HOOK_HEIGHT/2]) {
            cube([8, 6, 6], center = true);
        }
    }

    // Add chamfers on edges for print quality
    color([0.8, 0.8, 0.8]) {
        difference() {
            translate([0, 0, 0]) {
                cube([40, 35, 20], center = true);
            }
            translate([0, 0, 0]) {
                cube([38, 33, 18], center = true);
            }
        }
    }
}

// ============================================================================
// HELPER MODULES
// ============================================================================

// Base roller body with crown profile
module roller_body(diameter, width, crown) {
    // Create crown profile using cylinder with slight taper
    union() {
        // Main body cylinder
        cylinder(h = width, r = diameter/2 - crown, center = true, $fn = 64);

        // Crown rise (parabolic taper toward center)
        for (x = [-width/2 : 1 : width/2]) {
            offset_distance = abs(x) / (width/2);
            height_at_x = crown * (1 - offset_distance * offset_distance);
            translate([0, 0, x]) {
                cylinder(h = 1, r = diameter/2 - crown + height_at_x, center = true, $fn = 64);
            }
        }
    }
}

// D-cut bore for motor shaft gripping
module d_cut_bore(shaft_dia, flat_width, depth, length) {
    // Center bore for smooth rotation
    cylinder(h = length + TOLERANCE, r = shaft_dia/2, center = true, $fn = 32);
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

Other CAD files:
3d-parts/brackets.scad
3d-parts/brick_journey.scad
3d-parts/carousel_feeder.scad
3d-parts/electronics_enclosure.scad
3d-parts/entry_chute.scad
3d-parts/gate_module.scad
3d-parts/hybrid_assembly.scad
3d-parts/pancake_stack.scad
3d-parts/path_diagram.scad
3d-parts/scanning_chamber.scad
3d-parts/technical_drawing.scad

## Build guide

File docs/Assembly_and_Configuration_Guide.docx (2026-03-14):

LEGO AI Sorting Machine

Assembly & Configuration Guide

March 2026

# Table of Contents

(Update field after opening in Word: right-click → Update Field)

# Before You Begin

Required Tools & Equipment
Before assembly, gather the following tools. Most are standard workshop items; a few are specific to machine assembly and electronics work. You do not need every item for every step—a well-organized workspace will make the build faster and more enjoyable.

For mechanical assembly, you'll need hex keys (4mm for M5 bolts, 2mm for M3, 1.5mm for M2), a soldering iron (25–40W, with solder and flux), wire strippers (18–22 AWG), a crimping tool for Dupont connectors, a digital multimeter, flush cutters for filament trimming, and a small Phillips screwdriver. If cutting aluminum extrusion, have a miter saw with a metal-cutting blade or a hacksaw with a fine-tooth blade (32 TPI), plus a metal file for deburring.

Workspace setup matters. Choose a well-lit table or workbench with plenty of space (at least 2m × 1m). Use an ESD mat if you have one—it protects electronic components from static discharge. Organize small hardware (bolts, T-nuts, servo mounts) into labeled bins or containers so you can find items quickly. Have a small tray or magnetic pad for loose screws while working on subassemblies.

Safety is critical. Always unplug the power supply before making any wiring changes or removing components. Handle PCBs (the Raspberry Pi, PCA9685 boards, and stepper driver) by their edges only—avoid touching components. The 3D-printed PLA and PETG parts are strong but can crack if over-tightened; tighten bolts by hand and then add no more than 1/4 turn with a wrench. Wear safety glasses when cutting extrusion and use a dust mask when sanding or spray-painting 3D parts. Keep a first-aid kit nearby and work sober and alert.

Assembly Checklist

Item | Qty / Notes
Raspberry Pi 5 (8GB) | 1x — Raspberry Pi OS must be pre-installed
Pi Camera Module 3 | 1x — CSI ribbon cable included
NEMA 17 stepper motor | 1x — 1.8°/step, 40mm body length
TMC2209 stepper driver board | 1x
SG90 micro servos | 31x (buy 35 for spares)
PCA9685 PWM driver boards | 2x
2020 aluminum extrusion | 7.2m total (6× 1m lengths)
M5 T-nuts + bolts | 50+ pieces
M3 hardware kit | For servo mounting (100+ pieces)
608 ball bearings | 4x
Flat belt (70mm silicone) | 600mm length
LED strip (white, 5V) | 30cm
MOSFET module (IRLZ44N) | 1x
5V 10A power supply | 1x
12V 2A power supply | 1x
5V 5A USB-C power (Pi) | 1x
3D-printed parts | See design document for full print list
Small mirror (50×50mm) | 1x — for scanning chamber

# Phase 1 — Frame Assembly

## Cutting the Extrusion

Label each piece with masking tape before cutting to avoid confusion later. For cutting, use a miter saw equipped with a metal-cutting blade, or use a hacksaw with a fine-tooth blade (32 TPI minimum). Measure twice, cut once. After cutting, deburr all cut edges with a metal file and wipe away any chips with a damp cloth.

Extrusion Cut List

Piece | Length | Qty | Purpose
Vertical uprights | 700 mm | 4 | Main structural columns
Upper horizontal (width) | 400 mm | 2 | Belt support, top frame
Upper horizontal (depth) | 350 mm | 2 | Belt support, cross-bracing
Lower horizontal (width) | 400 mm | 2 | Bin tray support
Lower horizontal (depth) | 350 mm | 2 | Bin tray support
Mid horizontal (depth) | 350 mm | 2 | Gate tree mounting

## Assembling the Frame

1. Follow these steps to build a square, rigid frame:
2. Lay two 700 mm uprights parallel on a flat surface, 400 mm apart (outside-to-outside).
3. Connect at the top with one 400 mm horizontal using M5 T-nuts and corner brackets. Slide T-nuts into the slot BEFORE tightening bolts.
4. Connect at the bottom with another 400 mm horizontal. You now have an H-shaped side panel.
5. Repeat Steps 1–3 to create an identical second side panel.
6. Stand both panels upright and connect them with 350 mm depth pieces at the top, middle, and bottom on both sides (6 pieces total).
7. Check squareness: measure both diagonals on each face. They should match within 2 mm. Adjust before final tightening.

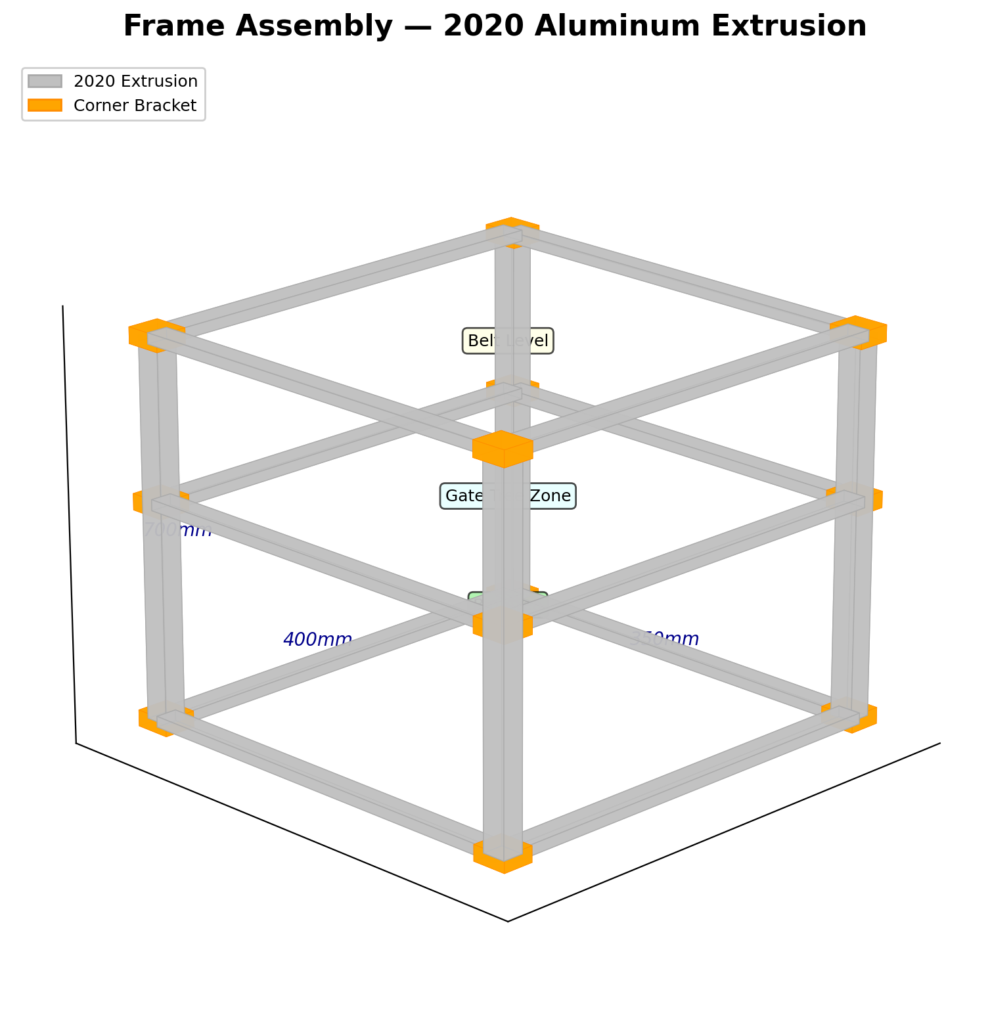
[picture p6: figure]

Figure 1: Aluminum extrusion frame — isometric view showing all members and zone labels.

## Tips for a Square Frame

- Use a machinist's square or large carpenter's square against each corner.
- Tighten bolts in a star pattern (opposite corners) to prevent racking.
- If diagonals don't match, loosen all bolts on the skewed face, push the long diagonal shorter, and retighten.
- Consider adding diagonal bracing (a short piece of extrusion corner-to-corner on the back face) if the frame wobbles.

# Phase 2 — Belt Assembly

## Roller Preparation

Press two 608 bearings into each printed roller (one for the drive roller, one for the idler). The bearing bores should be a tight press fit. If loose, use a tiny drop of Loctite 638 threadlocker. Place the rollers into their bearing housings and bolt the housings to the upper frame rails using M5 bolts and T-nuts. Verify both rollers spin freely by hand.

## Motor Installation

Mount the NEMA 17 stepper motor to its printed bracket using four M3×8 screws. Attach the bracket to one of the upper vertical uprights with M5 T-nuts. The motor shaft should align with the drive roller—use a short section of 5 mm-to-5 mm shaft coupler, or press the roller directly onto the motor shaft if the bore fits. Spin by hand to verify smooth rotation.

## Belt Installation & Tensioning

Loop the silicone belt around both rollers. Slide the idler roller toward the feed end until the belt is taut but not overly tight—you should be able to deflect it about 5 mm with a finger push at the midpoint. Lock the tensioner bracket. Spin the drive roller by hand and verify the belt tracks center. If it drifts, slightly angle the idler roller to correct.

## Side Rail Installation

Clip the two printed side rails onto the extrusion, centered over the scanning zone. They should stand 15 mm above the belt surface. These rails guide bricks through the camera scanning area.

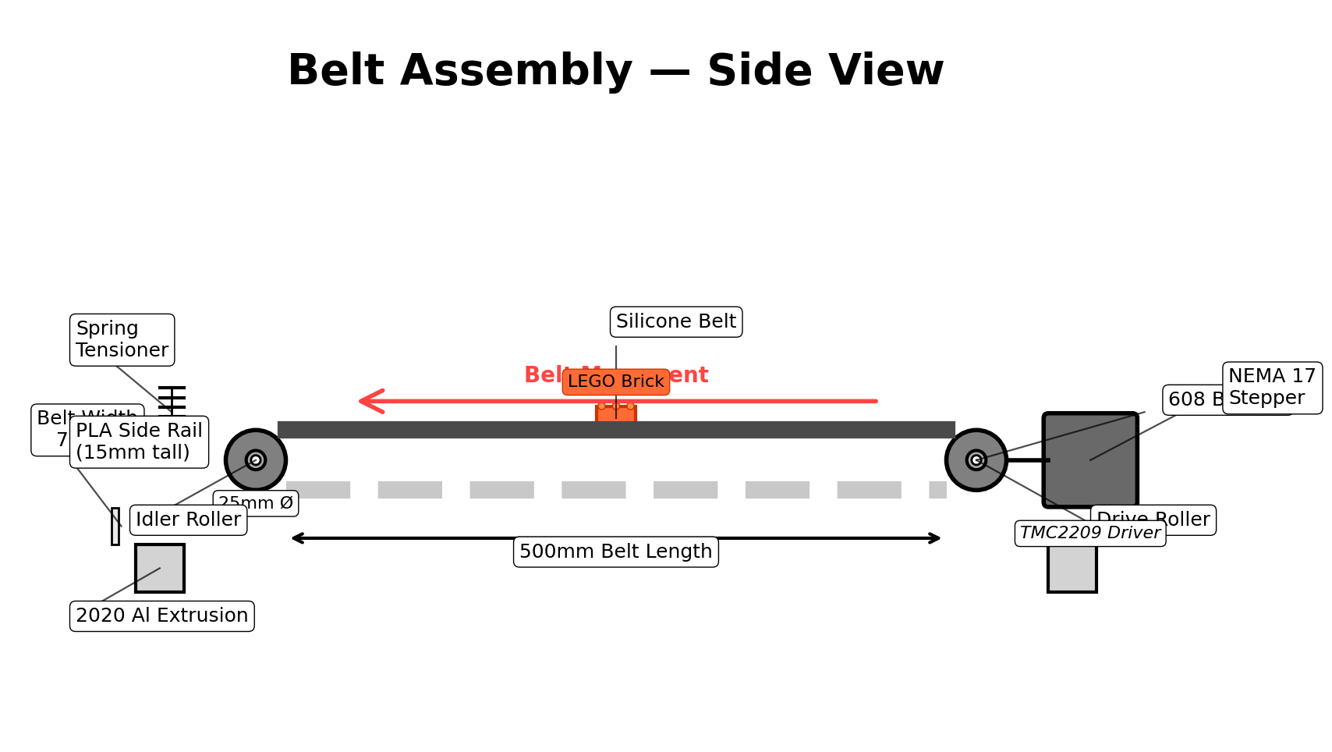
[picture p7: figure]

Figure 2: Belt assembly — side view showing drive/idler rollers, motor, and tensioning mechanism.

# Phase 3 — Scanning Chamber

## Printing the Chamber

Print the 4 chamber pieces in white PLA or PETG for durability:

- Base tray: Print as-is (open side up). Estimated time: ~2 hours. NO supports needed.
- Middle ring: Print as-is (it's a tube). Estimated time: ~1.5 hours. NO supports needed.
- Top cap: Print UPSIDE-DOWN (ceiling face on build plate). Estimated time: ~2 hours. NO supports needed.
- Mirror bracket: Print with flat face down (45° wedge). Estimated time: ~30 minutes. NO supports needed.

Print settings: Use 0.2 mm layer height, 20% infill, and 3 perimeters. All interior surfaces must be smooth with no support scarring—inspect before assembly.

## Chamber Assembly

8. Stack the pieces using the tongue-and-groove alignment features:
9. Place the base tray on a flat surface.
10. Lower the middle ring onto it—the tongue from the base fits into the groove on the middle ring.
11. Lower the top cap (right-side up now) onto the middle ring.
12. Secure with M3 bolts through the walls, or use cyanoacrylate glue on the tongue joints.
13. If the pieces are not printed in white, paint all interior surfaces matte white using flat white spray paint in light coats.

## Mirror Installation

Apply a thin line of hot glue or two-part epoxy to the back of the mirror bracket. Press it against the rear interior wall of the chamber. The bracket holds the 50×50 mm mirror at exactly 45°. Slide the mirror glass into the bracket slot. The 45° mirror allows the camera to capture both a top-down view and a side profile of the brick in a single frame.

## LED & Camera Installation

Press the LED strip (white, 5V) into the lip channel around the interior ceiling. Route the power wire out through the exit hole in the rear wall. Mount the Pi Camera Module 3 onto the camera mount bracket using M2 screws. Bolt the bracket to the mounting ring on top of the chamber. Verify the camera lens points straight down through the hole.

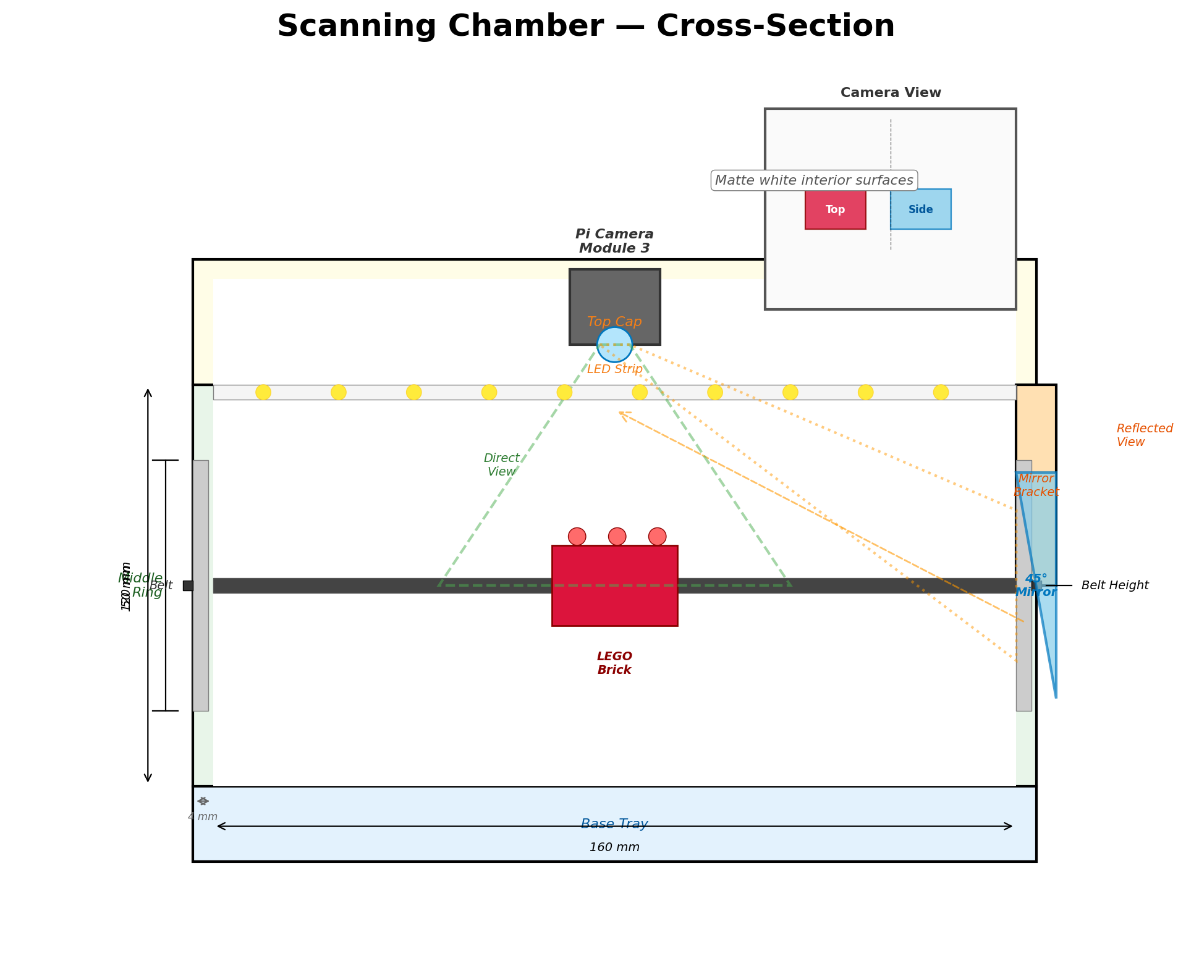
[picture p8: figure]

Figure 3: Scanning chamber cross-section — showing the 4-piece construction, camera, 45° mirror, and LED lighting.

## Testing the Scanner

Before proceeding, test the scanner and camera:

python main.py --test-camera

Place a LEGO brick inside the chamber. You should see both a top-down view and a side profile (reflected from the mirror) in the same camera frame. Adjust the mirror angle if the side view is cut off.

# Phase 4 — Gate Tree Assembly

## Printing the Modules

You need 31 identical Y-junction gate modules, 31 flap inserts, and 31 servo mount clips. Print in PETG for durability. At approximately 8 modules per batch, this takes about 4 batches over ~22 hours of print time. Each flap is small and prints in about 8 minutes. Verify all parts are printed at 0.2 mm layer height with no visible layer gaps.

## Individual Module Assembly

14. For each of the 31 modules, follow these steps:
15. Snap the two module halves together (if a 2-piece design).
16. Insert the lightweight PLA flap into the pivot slot.
17. Thread the pivot pin (a short piece of 1.75 mm filament works perfectly).
18. Snap the SG90 servo into the servo mount clip.
19. Attach the servo horn to the flap arm using the provided screw.
20. Test: manually rotate the servo—the flap should swing smoothly left and right with no binding.

## Building the Tree Structure

Build the gate tree from top to bottom:

- Level 1: Mount 1 gate module at the top, directly below the belt exit point.
- Level 2: Mount 2 gates below Level 1, each receiving one output.
- Level 3: Mount 4 gates below Level 2, connecting to Level 2 outputs.
- Level 4: Mount 8 gates below Level 3, connecting to Level 3 outputs.
- Level 5: Mount 16 gates at the bottom level, the final sorting layer.

Each level stacks below the previous using printed connector brackets. Use the gate tree frame brackets to secure the entire structure to the mid-height horizontal extrusion members. The whole tree angles approximately 30° from vertical for optimal brick flow.

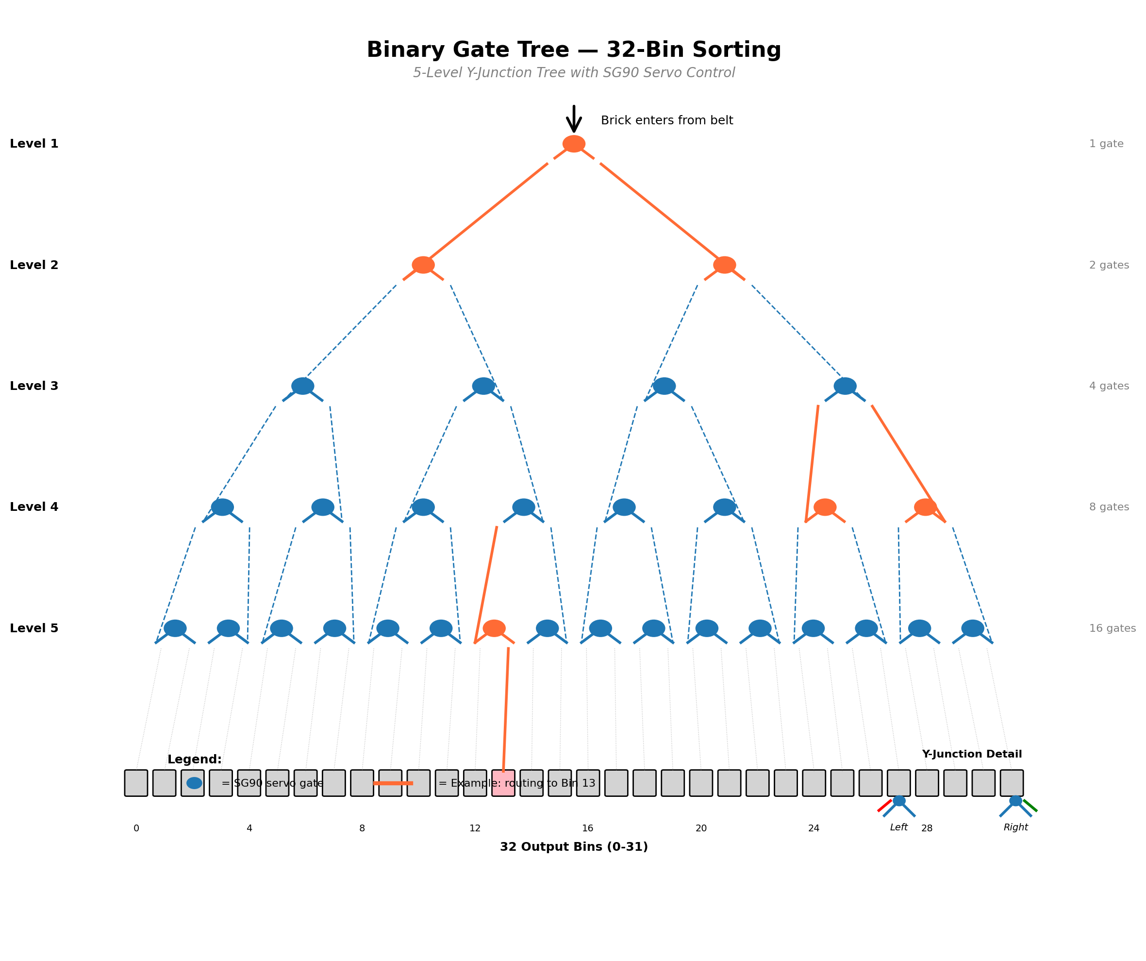
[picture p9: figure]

Figure 4: Binary gate tree — 5-level structure with 31 gates routing to 32 output bins. Orange path shows example routing to Bin 13.

## Output Bin Installation

Mount the 8 output bin brackets to the lower vertical uprights, spacing them evenly to hold your plastic bins across the 32 gate tree outputs. Each bin bracket has a front lip to prevent the bin from sliding off during operation.

# Phase 5 — Electronics & Wiring

## Electronics Enclosure

Mount the Raspberry Pi 5 inside the printed electronics enclosure using the built-in standoffs. This keeps the Pi protected and organized. Mount both PCA9685 PWM driver boards on their mount plates inside the enclosure as well.

## I2C Servo Drivers

Connect PCA9685 #1 to the Raspberry Pi's I2C bus:

- SDA → GPIO 2
- SCL → GPIO 3

Daisy-chain PCA9685 #2 from #1. Ensure the address jumper on #2 is set for 0x41 (solder jumper on the board). Connect servos 0–15 to board #1, servos 16–30 to board #2. Power both boards' V+ terminals from the 5V 10A supply.

## Stepper Driver

Wire the TMC2209 stepper driver:

- STEP → GPIO 17
- DIR → GPIO 18
- EN → GPIO 27
- VMOT → 12V supply
- GND → Common ground

Connect the NEMA 17 motor's 4 wires to the TMC2209 motor outputs (A1, A2, B1, B2). Check motor wiring with a multimeter—each coil pair should show 1–5 ohms of resistance.

## LED & Sensor Wiring

Connect the MOSFET gate to GPIO 12 through a 1 kΩ resistor. Connect the MOSFET drain to the LED strip negative terminal, and the source to ground. Connect the LED strip positive to the 5V servo supply. For the optional IR break-beam sensor, connect the signal line to GPIO 25 with a 10 kΩ pull-up resistor to 3.3V.

## Power & Grounding

CRITICAL: Connect all three power supply grounds together on a common ground bus. Use thick wire (18 AWG or larger) for the servo 5V supply—31 servos can draw significant current during simultaneous moves. Keep all power wires short and secure them with cable ties. Verify polarity twice before connecting power.

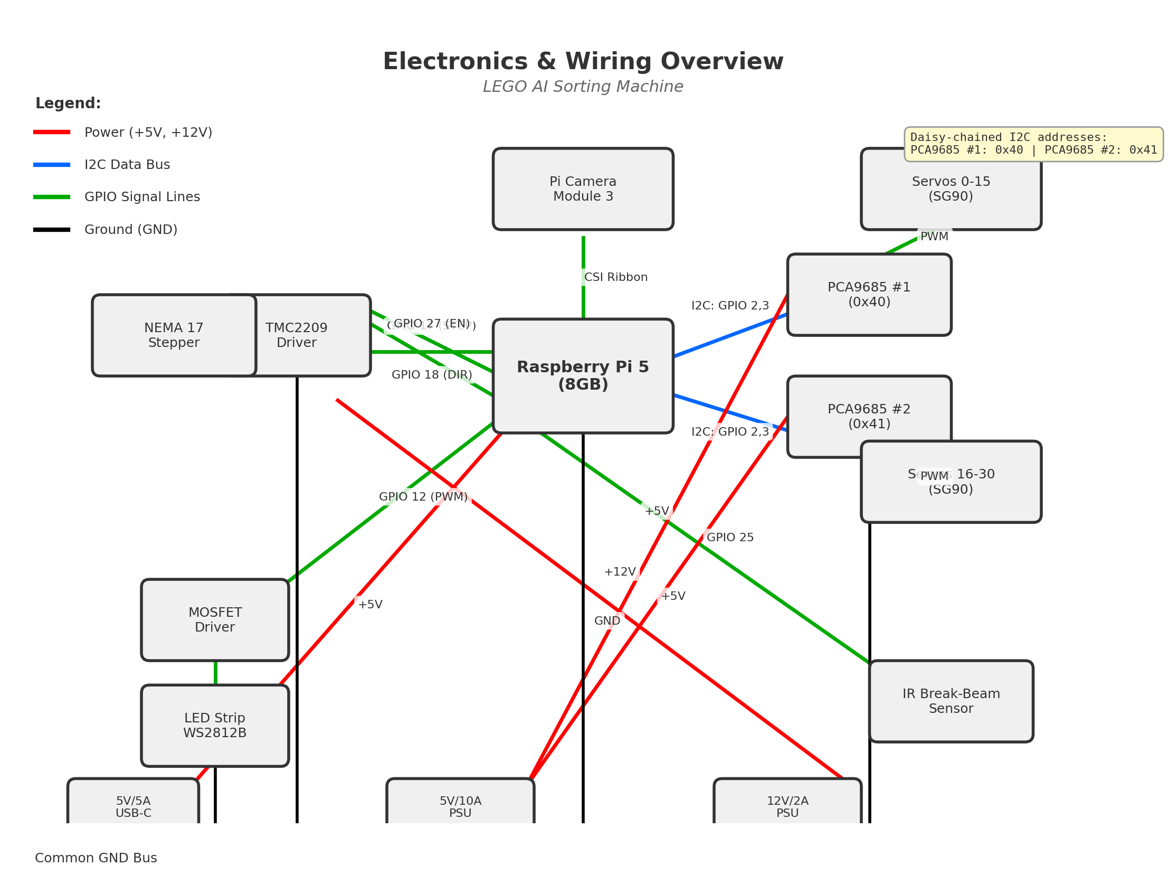
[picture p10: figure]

Figure 5: Electronics wiring overview — block diagram showing all connections, GPIO pins, and power distribution.

# Software Setup

## Raspberry Pi OS

Install Raspberry Pi OS (64-bit Bookworm) using the Raspberry Pi Imager tool. After installation, boot the Pi and open a terminal. Run 'sudo raspi-config' to enable: the camera interface, I2C, and SSH for remote access. Connect to WiFi during setup—it is required for Brickognize API calls.

## Installing Dependencies

Install Python dependencies:

cd ~/lego-sorter
pip install -r requirements.txt --break-system-packages
pip install RPi.GPIO adafruit-circuitpython-pca9685 adafruit-circuitpython-motor --break-system-packages

## Configuration (config.yaml)

Edit config.yaml in the project root directory. Key configuration sections:

- belt: step_pin, dir_pin, speed_mm_per_sec (start at 35), steps_per_mm (calibrate this!)
- scanner: resolution, motion_threshold (start at 2500, lower = more sensitive), led_brightness
- classifier: confidence_threshold (start at 0.65, raise to 0.75 once tuned), unknown_bin (31)
- sorter: pca9685_addresses [0x40, 0x41], servo_min_pulse/max_pulse, left_angle/right_angle
- rebrickable: api_key (get free key at rebrickable.com/api/), target_sets list

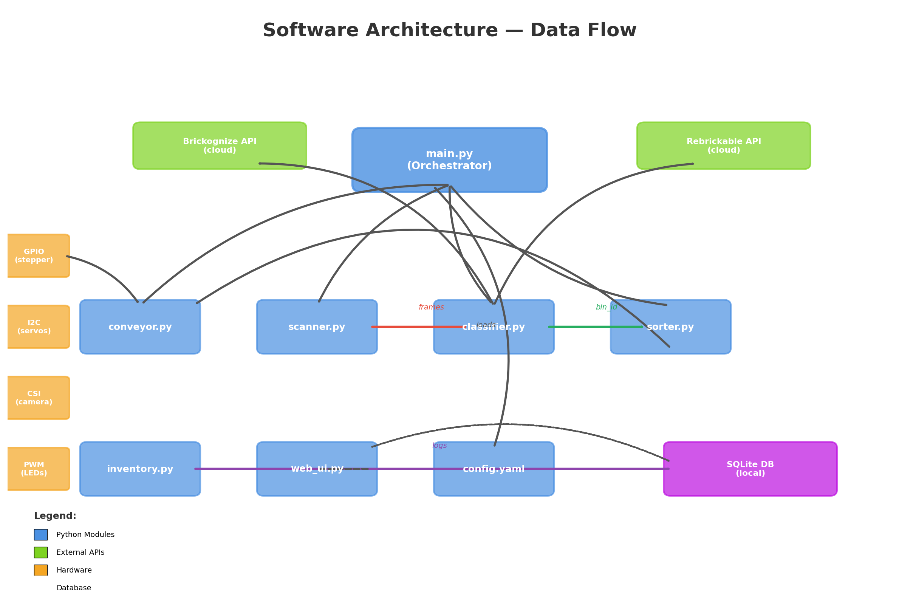
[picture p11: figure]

Figure 6: Software architecture — data flow between modules, APIs, and hardware interfaces.

# Bin Assignment Configuration

The bin_assignments section in config.yaml controls how sorted bricks are routed to output bins. The classifier extracts a category name from the Brickognize response, then performs a prefix match against the bin_assignments keys. The first matching key determines the bin. Keep bin 31 reserved for unknowns or unusable parts.

Default Bin Assignments (Sample)

Category Prefix | Bin #
Plate | 0–3
Brick_2x4 | 4–7
Brick_2x2 | 8–11
Brick_1x4 | 12–14
Brick_1x2 | 15–18
Brick_1x1 | 19–22
Slope | 23–25
Minifig_Head | 26
Minifig_Body | 27
Minifig_Legs | 28
Wheel | 29
Axle | 30
Unknown/Unsorted | 31

Tips:

- Start with the defaults. After your first sorting session, check which bins overflow.
- Split high-volume categories across two or more bins.
- If building a specific set, organize by set components rather than part type.
- Always reserve bin 31 for unknowns—it will catch classification edge cases.

# First Run & Calibration

## Component Tests

Run each test mode to verify individual components:

python main.py --test-camera: Verify you see a clear image with both top-down and side profile views.

python main.py --test-classify photo.jpg: Test on a known brick; verify correct identification.

python main.py --test-gates: Cycles all 31 servos left and right; verify smooth mechanical movement.

python main.py --web-only: Starts the dashboard without hardware; verify web interface loads.

## Calibration Steps

Belt speed: Place a brick on the belt, time how long to traverse 100 mm. Adjust steps_per_mm until actual distance matches.

Camera focus: Auto-focus should handle this, but verify sharpness on the dashboard camera feed. Clean the lens if fuzzy.

Motion threshold: Lower the threshold if bricks pass without triggering. Raise it if ambient vibration causes false triggers.

Confidence threshold: Run 20+ test bricks. If too many go to 'unknown', lower the threshold. If misidentifications are common, raise it.

Gate calibration: Verify each servo's left_angle and right_angle actually direct bricks fully left/right. Adjust by 5° increments.

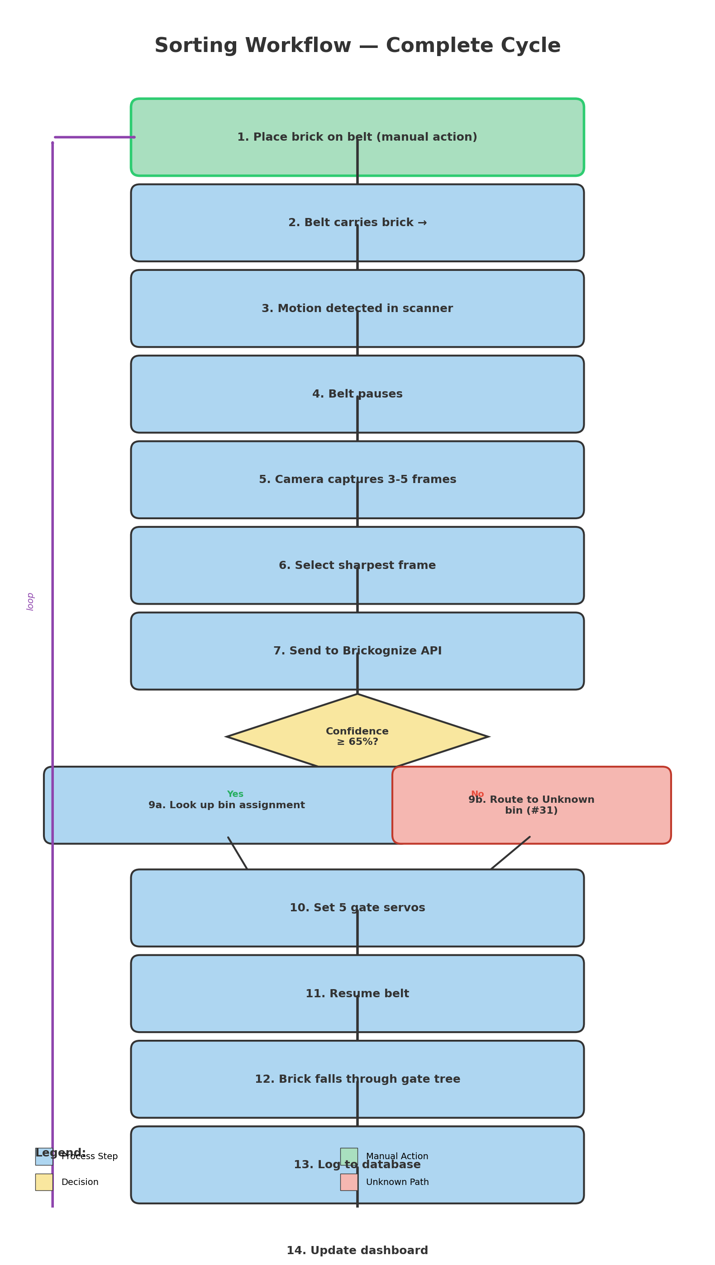
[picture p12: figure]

Figure 7: Complete sorting workflow — from manual brick placement through classification, routing, and logging.

# Web Dashboard Guide

Open a web browser on any device connected to the same WiFi network. Navigate to http://<pi-ip>:5000 (replace <pi-ip> with your Raspberry Pi's IP address, visible in raspi-config or using 'hostname -I'). The dashboard displays:

- Live camera feed (updates every 2 seconds)
- Real-time statistics (total sorted, bricks per minute, average confidence)
- Set completion progress bars for each registered Rebrickable set
- Control buttons (Start/Stop/Pause, belt speed slider, individual gate test buttons)

To load a Rebrickable set: In the Rebrickable section, enter the set number (e.g., '42100-1') and click 'Load'. The system pulls the full parts list from Rebrickable. As bricks are sorted, the progress bar fills. Click 'Export Missing CSV' to generate a BrickLink-compatible CSV file for ordering missing parts.

# Troubleshooting

Reference this table when encountering issues:

Symptom | Likely Cause | Solution
Belt doesn't move | ENABLE pin (active low) not pulled LOW, 12V supply missing, or TMC2209 wiring error | Check ENABLE pin is LOW, verify 12V supply voltage with multimeter, inspect motor wiring
Servos don't respond | I2C address conflict, 5V servo supply not connected, or address jumpers set wrong | Run 'i2cdetect -y 1' to see all I2C addresses, verify 5V supply on both PCA9685 boards, check address jumpers
Camera feed is black | CSI ribbon cable loose, camera not enabled in raspi-config, or lens obstruction | Reseat the CSI ribbon, run raspi-config and enable camera, clean the lens
API returns low confidence | Poor lighting, dirty mirror, brick not centered, or wrong orientation | Increase LED brightness in config, clean mirror with soft cloth, adjust brick position, try different angles
Bricks jam in gate tree | Flap clearance too tight, rough edges, shallow tree angle, or servo angles wrong | Sand flap edges smooth, increase tree angle to ~30°, adjust servo left_angle/right_angle ±5°
Dashboard won't load | Flask server not running, wrong Pi IP, or firewall blocking port 5000 | Verify Flask is running, use 'hostname -I' to get Pi IP, check firewall rules allow port 5000
Wrong bin assignment | Category name mismatch or incorrect prefix in config.yaml | Check classifier.py output log for exact category names, update bin_assignments section

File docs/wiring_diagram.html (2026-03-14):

# LEGO AI Sorting Machine

Comprehensive Wiring Diagram & Reference Guide

Critical Safety Notes

Power sequencing: Always connect 12V stepper supply first, then 5V servo supply, then Raspberry Pi USB-C last

Common ground: All three power supplies MUST share a common ground reference

Current limits: Ensure wire gauges match specifications (18-20 AWG for low-current signals, 16 AWG for 5V servo rail)

Cable management: Keep signal lines away from high-current power rails to minimize EMI

GPIO voltage: Raspberry Pi GPIO operates at 3.3V; ensure pullup/pulldown resistors on inputs

← Scroll horizontally to view full diagram →

Wire Color Guide

5V Power Rail

12V Motor Supply

Ground (GND)

I2C Bus (SDA/SCL)

STEP Signal

DIR Signal

ENABLE Signal

PWM (LED Control)

IR Sensor Input

CSI Ribbon (Camera)

USB-C Power

Interactive

Click any component to highlight its connections

Raspberry Pi 5 GPIO Connections

Pin # | GPIO # | Function | Direction
3 | GPIO 2 | I2C SDA | Bidirectional
5 | GPIO 3 | I2C SCL | Bidirectional
11 | GPIO 17 | STEP Signal | Output (3.3V)
12 | GPIO 18 | DIR Signal | Output (3.3V)
32 | GPIO 12 | PWM (LED Strip) | Output PWM
37 | GPIO 27 | ENABLE (TMC2209) | Output (Active Low)
22 | GPIO 25 | IR Sensor Input | Input (Optional)
— | CSI 0 | Camera Interface | Ribbon Cable

I2C Addresses & Configuration

Device | Address | Channels | Purpose
PCA9685 #1 | 0x40 | 0-15 | Gates 0-15 (SG90)
PCA9685 #2 | 0x41 | 0-14 | Gates 16-30 (SG90)
Both connected via I2C at GPIO 2 (SDA) & GPIO 3 (SCL)

Power Budget & Current Requirements

Component | Voltage | Qty | Current/Each | Total Current | Power Supply
Raspberry Pi 5 | 5V | 1 | ~3.5A peak | 3.5A | 5V 5A USB-C
PCA9685 #1 (board) | 5V | 1 | ~0.1A | 0.1A | 5V 10A Servo PSU
PCA9685 #2 (board) | 5V | 1 | ~0.1A | 0.1A
SG90 Servos (inactive) | 5V | 31 | ~0.05A @ rest | 1.55A
SG90 Servos (moving) | 5V | 31 | ~0.5A peak | 5-8A (staggered)
LED Strip (max brightness) | 5V | 1 | ~2A | 2A
Total 5V Budget: | | | | ~7-9A sustained
NEMA 17 Stepper | 12V | 1 | ~1.2A (RMS) | 1.2A | 12V 2A PSU
Note: Servo movements are staggered in software to prevent inrush current. Peak current is managed.

Recommended Wire Gauges & Standards

Circuit Type | Voltage/Current | Wire Gauge | Notes
GPIO Signals (STEP/DIR/EN) | 3.3V, <1mA | 22 AWG | Keep short, away from power rails
I2C Bus (SDA/SCL) | 3.3V, <5mA | 22 AWG | 4.7kΩ pullup resistors recommended
5V Servo Power Rail | 5V, ~9A peak | 16 AWG | Use thicker wire for long runs
12V Motor Power | 12V, 1.2A | 18 AWG | Stepper motor power line
Ground Return (GND) | Common Reference | 16 AWG minimum | Must connect all supplies together
PWM LED Control | 3.3V PWM signal | 22 AWG | MOSFET gate input

Servo Channel Allocation (SG90 servos)

Gate # | Board | Channel | Gate # | Board | Channel
0-7 | PCA9685 #1 (0x40) | 0-7 | 16-23 | PCA9685 #2 (0x41) | 0-7
8-15 | PCA9685 #1 (0x40) | 8-15 | 24-30 | PCA9685 #2 (0x41) | 8-14
All servos receive 5V power from PCA9685 boards; PWM signals control position (90°-180° typical range)

Build & Verification Checklist

Before Power-On:

☐ All ground connections verified (3 PSUs share common GND)
☐ 5V servo rail properly sized (16 AWG minimum)
☐ 12V motor supply isolated from 5V rails
☐ I2C pullup resistors installed (4.7kΩ on SDA/SCL)
☐ TMC2209 microstep configuration verified
☐ MOSFET gate resistor installed (10kΩ recommended)
☐ All GPIO connections double-checked against pinout

Power-On Sequence:

1. Connect 12V stepper supply (no current should flow yet)
2. Connect 5V servo supply (PCA9685 boards power up)
3. Connect Raspberry Pi via USB-C last
4. Verify no unusual heat or smoke

Testing:

☐ I2C scan finds both PCA9685 boards (0x40 & 0x41)
☐ Servo test sweeps all 31 gates smoothly
☐ Stepper motor rotates in both directions
☐ LED strip PWM control responds to brightness commands
☐ IR sensor (if installed) detects bricks at exit

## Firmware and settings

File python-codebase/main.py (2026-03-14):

#!/usr/bin/env python3
"""
LEGO AI Sorting Machine — Main Controller
==========================================
Entry point that orchestrates all subsystems:
  - Conveyor belt (stepper motor with optional encoder)
  - Scanner (camera + motion detection, multi-angle support)
  - Classifier (Brickognize API with local cache)
  - Sorter (binary gate tree, multiple sort modes)
  - Inventory (SQLite + Rebrickable + analytics)
  - Web dashboard (Flask, OTA config, export)

Usage:
    python main.py                  # Run the full system
    python main.py --test-gates     # Test all servo gates
    python main.py --test-camera    # Test camera capture
    python main.py --test-classify  # Test classification on a photo
    python main.py --test-rescan    # Test rescan workflow on an image
    python main.py --web-only       # Start web dashboard without hardware
    python main.py --sort-mode color  # Start with color sorting
"""
import sys
import time
import signal
import threading
import argparse
import collections
from typing import Optional

import yaml

from conveyor import Conveyor
from scanner import Scanner
from classifier import Classifier
from sorter import Sorter
from inventory import Inventory
from web_ui import create_app
from logger import get_logger

log = get_logger("main")

# ── CENTRALIZED GPIO SETUP ────────────────────────────────
PI_GPIO = None
try:
    import RPi.GPIO as _GPIO
    _GPIO.setmode(_GPIO.BCM)
    PI_GPIO = _GPIO
except (ImportError, RuntimeError):
    pass


class RetryQueue:
    """Queue for bricks that failed API classification.

    Holds image + metadata for deferred re-classification when the
    API becomes available again. Max 20 entries to bound memory.
    """

    def __init__(self, max_size: int = 20) -> None:
        self.queue = collections.deque(maxlen=max_size)
        self._lock = threading.Lock()

    def add(self, image, metadata: dict) -> None:
        """Add a failed classification to the retry queue."""
        with self._lock:
            self.queue.append({"image": image, "metadata": metadata,
                               "added_at": time.time()})
            log.info(f"Retry queue: {len(self.queue)} pending")

    def get_all(self) -> list:
        """Drain and return all queued items."""
        with self._lock:
            items = list(self.queue)
            self.queue.clear()
            return items

    @property
    def size(self) -> int:
        """Number of items in the queue."""
        return len(self.queue)


class SortingMachine:
    """Main controller that orchestrates the sorting pipeline.

    Attributes:
        config: Loaded configuration dictionary.
        state: Current machine state string.
        sort_mode: Active sort mode (delegates to Sorter).
    """

    def __init__(self, config_path: str = "config.yaml") -> None:
        with open(config_path, "r") as f:
            self.config = yaml.safe_load(f)
        self._config_path = config_path

        log.info("=" * 60)
        log.info("  LEGO AI Sorting Machine v3")
        log.info("=" * 60)

        # Initialize all subsystems
        self.conveyor = Conveyor(self.config)
        self.scanner = Scanner(self.config)
        self.classifier = Classifier(self.config)
        self.sorter = Sorter(self.config)
        self.inventory = Inventory(self.config)

        # State management
        self.state: str = "idle"
        self._running: bool = False
        self._sort_thread: Optional[threading.Thread] = None

        # Rescan statistics
        self.rescan_attempts: int = 0
        self.rescan_successes: int = 0

        # Error recovery
        self._retry_queue = RetryQueue(max_size=20)
        self._retry_thread: Optional[threading.Thread] = None
        self._api_healthy: bool = True

        # Graceful shutdown
        signal.signal(signal.SIGINT, self._signal_handler)
        signal.signal(signal.SIGTERM, self._signal_handler)

        # Power sequencing
        self._power_sequence()
        log.info(f"Bins: {self.sorter.num_bins}")
        log.info(f"Gate tree: {self.sorter.num_levels} levels, "
                 f"{self.sorter.num_gates} gates")
        log.info(f"Sort mode: {self.sorter.sort_mode}")
        log.info(f"API: {self.classifier.api_url}")

    @property
    def sort_mode(self) -> str:
        """Current sort mode (delegates to Sorter)."""
        return self.sorter.sort_mode

    def _power_sequence(self) -> None:
        """Enable servo power relay after hardware initialization."""
        servo_cfg = self.config.get("sorter", {})
        servo_power_pin = servo_cfg.get("servo_power_pin", 22)
        self._servo_power_pin: Optional[int] = None

        if PI_GPIO is None:
            log.info("Servo power sequencing: not on Raspberry Pi")
            return

        try:
            PI_GPIO.setup(servo_power_pin, PI_GPIO.OUT)
            PI_GPIO.output(servo_power_pin, PI_GPIO.HIGH)
            self._servo_power_pin = servo_power_pin
            log.info(f"Servo power enabled (GPIO {servo_power_pin})")
        except RuntimeError as e:
            log.error(f"Servo power sequencing failed: {e}")

    def start(self) -> None:
        """Start the sorting machine."""
        if self._running:
            return

        log.info("Starting sorting machine...")

        if not self.scanner.initialize():
            log.warning("Camera initialization failed")

        self._running = True
        self.state = "running"

        self.conveyor.start()

        # Start sorting loop
        self._sort_thread = threading.Thread(target=self._sorting_loop,
                                              daemon=True)
        self._sort_thread.start()

        # Start retry processor
        self._retry_thread = threading.Thread(target=self._retry_loop,
                                               daemon=True)
        self._retry_thread.start()

        log.info("Machine running — place bricks on the belt!")

    def stop(self) -> None:
        """Stop the sorting machine."""
        log.info("Stopping...")
        self._running = False
        self.state = "idle"
        self.conveyor.stop()
        if self._sort_thread:
            self._sort_thread.join(timeout=5)
        if self._retry_thread:
            self._retry_thread.join(timeout=3)
        log.info("Machine stopped")

    def _classify_with_rescan(self, initial_frame) -> tuple:
        """Classify a brick with automatic rescan on low confidence.

        Belt must be PAUSED when called. Belt remains PAUSED on return.

        Args:
            initial_frame: Primary camera frame (BGR numpy array).

        Returns:
            Tuple of (ClassificationResult, bin_number).
        """
        # Get secondary frame if available
        secondary = self.scanner.capture_secondary()

        # First classification attempt (with multi-angle)
        cropped = self.scanner.crop_brick(initial_frame)
        result = self.classifier.classify(cropped, secondary_image=secondary)

        if not result.is_confident and not result.needs_review:
            log.info("Low confidence — attempting re-scan...")
            self.rescan_attempts += 1

            try:
                self.conveyor.resume()
                time.sleep(0.05)
                self.conveyor.pause()
                time.sleep(0.15)

                frame_2 = self.scanner.capture_brick()
                if frame_2 is not None:
                    cropped_2 = self.scanner.crop_brick(frame_2)
                    secondary_2 = self.scanner.capture_secondary()
                    result_2 = self.classifier.classify(cropped_2,
                                                         secondary_image=secondary_2)

                    if result_2.is_confident or result_2.needs_review:
                        self.rescan_successes += 1
                        log.info("Rescan successful!")
                        result = result_2
                else:
                    log.warning("Rescan capture failed, using first result")
            except Exception as e:
                log.error(f"Rescan error: {e}", extra={"error": str(e)})
            finally:
                self.conveyor.pause()

        # Determine bin assignment based on sort mode
        if result.is_confident:
            bin_num = self.sorter.get_bin_for_part(
                result.category, color=result.color, part_id=result.part_id)
        elif result.needs_review:
            bin_num = self.classifier.review_bin
        else:
            bin_num = self.sorter.unknown_bin

        return result, bin_num

    def _sorting_loop(self) -> None:
        """Main sorting loop — runs in a background thread."""
        consecutive_errors = 0

        while self._running:
            try:
                if self.scanner.detect_motion():
                    self.state = "scanning"
                    log.info("Brick detected!")

                    self.conveyor.pause()
                    time.sleep(0.15)

                    frame = self.scanner.capture_brick()
                    if frame is None:
                        log.warning("Capture failed, resuming belt")
                        self.conveyor.resume()
                        self.state = "running"
                        continue

                    self.state = "classifying"
                    result, bin_num = self._classify_with_rescan(frame)

                    # If API is down, queue for retry
                    if (not result.is_confident and not result.needs_review
                            and not self._api_healthy):
                        self._retry_queue.add(frame, {"timestamp": time.time()})
                        bin_num = self.sorter.unknown_bin

                    self.state = "sorting"
                    self.sorter.route_to_bin(bin_num)

                    self.conveyor.resume()

                    self.inventory.log_part(
                        part_id=result.part_id,
                        part_name=result.part_name,
                        color=result.color,
                        category=result.category,
                        confidence=result.confidence,
                        bin_number=bin_num,
                        image_url=result.image_url,
                        needs_review=result.needs_review,
                        sort_mode=self.sorter.sort_mode,
                    )

                    self.state = "running"
                    stats = self.inventory.get_stats()
                    log.info(f"{result.part_name or 'Unknown'} -> Bin {bin_num} "
                             f"({stats['total_sorted']} total, "
                             f"{stats['parts_per_minute']}/min)",
                             extra={"part_id": result.part_id,
                                    "bin_number": bin_num,
                                    "confidence": result.confidence})

                    consecutive_errors = 0
                    self._api_healthy = True
                    time.sleep(0.3)

                else:
                    time.sleep(0.05)

            except Exception as e:
                consecutive_errors += 1
                log.error(f"Sorting loop error: {e}", extra={"error": str(e)})
                import traceback
                traceback.print_exc()
                self.conveyor.resume()
                self.state = "running"

                if consecutive_errors >= 3:
                    self._api_healthy = False
                    log.warning("Multiple errors — marking API unhealthy")

                time.sleep(1)

    def _retry_loop(self) -> None:
        """Background thread that retries failed classifications every 30s."""
        while self._running:
            time.sleep(30)

            if self._retry_queue.size == 0 or not self._api_healthy:
                continue

            items = self._retry_queue.get_all()
            log.info(f"Retrying {len(items)} queued classifications...")

            for item in items:
                try:
                    image = item["image"]
                    cropped = self.scanner.crop_brick(image)
                    result = self.classifier.classify(cropped)

                    if result.is_confident:
                        bin_num = self.sorter.get_bin_for_part(
                            result.category, color=result.color,
                            part_id=result.part_id)
                        self.inventory.log_part(
                            part_id=result.part_id,
                            part_name=result.part_name,
                            color=result.color,
                            category=result.category,
                            confidence=result.confidence,
                            bin_number=bin_num,
                            image_url=result.image_url,
                            sort_mode=self.sorter.sort_mode,
                        )
                        log.info(f"Retry succeeded: {result.part_name}")
                except Exception as e:
                    log.warning(f"Retry failed: {e}")
                    self._api_healthy = False
                    break

    def update_config(self, section: str, key: str, value) -> bool:
        """Update a configuration value at runtime and save to disk.

        Args:
            section: Top-level config section (e.g. 'belt', 'classifier').
            key: Configuration key within the section.
            value: New value to set.

        Returns:
            True if update was successful.
        """
        if section not in self.config:
            log.warning(f"Unknown config section: {section}")
            return False

        old_value = self.config[section].get(key)
        self.config[section][key] = value
        log.info(f"Config updated: {section}.{key} = {value} (was {old_value})")

        # Apply live changes
        if section == "belt" and key == "speed_mm_per_sec":
            self.conveyor.set_speed(float(value))
        elif section == "classifier" and key == "confidence_threshold":
            self.classifier.confidence_threshold = float(value)
        elif section == "classifier" and key == "review_threshold":
            self.classifier.review_threshold = float(value)
        elif section == "scanner" and key == "led_brightness":
            try:
                if self.scanner._led_pwm:
                    self.scanner._led_pwm.ChangeDutyCycle(int(value))
            except Exception:
                pass

        # Save to disk
        try:
            with open(self._config_path, 'w') as f:
                yaml.dump(self.config, f, default_flow_style=False,
                          sort_keys=False)
            return True
        except Exception as e:
            log.error(f"Failed to save config: {e}")
            return False

    def _signal_handler(self, signum, frame) -> None:
        """Handle Ctrl+C gracefully."""
        log.info("Shutdown signal received...")
        self.shutdown()
        sys.exit(0)

    def shutdown(self) -> None:
        """Clean shutdown of all subsystems."""
        self.stop()

        if self._servo_power_pin is not None and PI_GPIO is not None:
            try:
                PI_GPIO.output(self._servo_power_pin, PI_GPIO.LOW)
            except RuntimeError:
                pass

        self.scanner.cleanup()
        self.conveyor.cleanup()
        self.sorter.cleanup()
        self.inventory.cleanup()

        if PI_GPIO is not None:
            try:
                PI_GPIO.cleanup()
            except RuntimeError:
                pass

        log.info("All subsystems shut down cleanly")

    def run_web_dashboard(self) -> None:
        """Start the Flask web dashboard."""
        web_cfg = self.config.get("web", {})
        app = create_app(self)
        log.info(f"Web dashboard: http://0.0.0.0:{web_cfg.get('port', 5000)}")
        log.info("Open in browser on any device on your network")
        app.run(
            host=web_cfg.get("host", "0.0.0.0"),
            port=web_cfg.get("port", 5000),
            debug=web_cfg.get("debug", False),
            use_reloader=False,
        )


# ── CLI ENTRY POINT ─────────────────────────────────────────

def main() -> None:
    parser = argparse.ArgumentParser(description="LEGO AI Sorting Machine")
    parser.add_argument("--config", default="config.yaml",
                       help="Path to config file")
    parser.add_argument("--test-gates", action="store_true",
                       help="Test all servo gates")
    parser.add_argument("--test-camera", action="store_true",
                       help="Test camera capture")
    parser.add_argument("--test-classify", metavar="IMAGE",
                       help="Test classification on an image file")
    parser.add_argument("--test-rescan", metavar="IMAGE",
                       help="Test rescan workflow (classifies twice)")
    parser.add_argument("--web-only", action="store_true",
                       help="Start web dashboard without hardware")
    parser.add_argument("--sort-mode",
                       choices=["part", "color", "category", "set"],
                       help="Set the sort mode")
    args = parser.parse_args()

    machine = SortingMachine(args.config)

    if args.sort_mode:
        machine.sorter.set_sort_mode(args.sort_mode)

    if args.test_gates:
        log.info("Testing all servo gates...")
        machine.sorter.test_all_gates()
        for i in range(machine.sorter.num_bins):
            log.info(f"  Testing bin {i}...")
            machine.sorter.test_bin(i)
            time.sleep(0.5)
        log.info("Gate test complete!")
        machine.shutdown()

    elif args.test_camera:
        log.info("Testing camera...")
        machine.scanner.initialize()
        frame = machine.scanner.capture_brick()
        if frame is not None:
            try:
                import cv2
                cv2.imwrite("test_capture.jpg", frame)
                log.info("Saved test_capture.jpg")
            except ImportError:
                log.info(f"Captured frame: {frame.shape}")
        if machine.scanner.has_secondary:
            sec = machine.scanner.capture_secondary()
            if sec is not None:
                try:
                    import cv2
                    cv2.imwrite("test_secondary.jpg", sec)
                    log.info("Saved test_secondary.jpg")
                except ImportError:
                    log.info(f"Secondary frame: {sec.shape}")
        machine.shutdown()

    elif args.test_classify:
        log.info(f"Testing classification on {args.test_classify}...")
        try:
            import cv2
            image = cv2.imread(args.test_classify)
            if image is not None:
                result = machine.classifier.classify(image)
                log.info(f"Result: {result}")
                log.info(f"Category: {result.category}")
                log.info(f"Bin (part): "
                         f"{machine.sorter.get_bin_for_part(result.category)}")
                log.info(f"Bin (color): "
                         f"{machine.sorter.get_bin_for_part(result.category, color=result.color)}")
                if result.needs_review:
                    log.info("** This part needs manual review **")
                if result.alternatives:
                    log.info("Alternatives:")
                    for alt in result.alternatives:
                        log.info(f"  - {alt['part_name']} "
                                 f"({alt['confidence']:.2f})")
            else:
                log.error(f"Could not read image: {args.test_classify}")
        except ImportError:
            log.error("OpenCV required for image classification test")
        machine.shutdown()

    elif args.test_rescan:
        log.info(f"Testing rescan workflow on {args.test_rescan}...")
        try:
            import cv2
            image = cv2.imread(args.test_rescan)
            if image is not None:
                log.info("First classification attempt:")
                cropped_1 = machine.scanner.crop_brick(image)
                result_1 = machine.classifier.classify(cropped_1)
                log.info(f"  Part: {result_1.part_name or 'Unknown'}")
                log.info(f"  Confidence: {result_1.confidence:.4f}")
                log.info(f"  Needs review: {result_1.needs_review}")

                log.info("Second classification attempt:")
                result_2 = machine.classifier.classify(cropped_1)
                log.info(f"  Part: {result_2.part_name or 'Unknown'}")
                log.info(f"  Confidence: {result_2.confidence:.4f}")

                if result_1.is_confident:
                    log.info(f"First succeeded: {result_1.part_name}")
                elif result_2.is_confident:
                    log.info(f"Second succeeded: {result_2.part_name}")
                else:
                    log.info("Both failed — would route to unknown bin")
            else:
                log.error(f"Could not read image: {args.test_rescan}")
        except ImportError:
            log.error("OpenCV required for rescan test")
        machine.shutdown()

    elif args.web_only:
        log.info("Starting web dashboard (no hardware)...")
        machine.run_web_dashboard()

    else:
        machine.start()
        for set_num in machine.inventory.target_sets:
            machine.inventory.load_set(set_num)
        machine.run_web_dashboard()


if __name__ == "__main__":
    main()

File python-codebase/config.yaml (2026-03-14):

# ============================================================
# LEGO AI Sorting Machine — Configuration (v3)
# ============================================================
# Edit these values to match your hardware setup.
# All pin numbers are BCM GPIO numbers.
# Settings can also be changed from the web dashboard (Settings tab).
# ============================================================

# ── CONVEYOR BELT ───────────────────────────────────────────
belt:
  step_pin: 17          # GPIO pin for stepper STEP signal
  dir_pin: 18           # GPIO pin for stepper DIR signal
  enable_pin: 27        # GPIO pin for stepper ENABLE (active low)
  speed_mm_per_sec: 35  # Belt speed in mm/s
  steps_per_mm: 5       # Calibrate: steps needed to move belt 1mm
  pause_after_classify_ms: 300  # Extra pause after classification before resuming
  # Optional rotary encoder for closed-loop speed control
  encoder:
    enabled: false               # Set true to enable encoder feedback
    pin_a: 23                    # Encoder channel A GPIO pin
    pin_b: 24                    # Encoder channel B GPIO pin
    pulses_per_rev: 600          # Encoder pulses per revolution
    roller_circumference_mm: 75.4  # Drive roller circumference in mm

# ── SCANNING CHAMBER ────────────────────────────────────────
scanner:
  camera_index: 0           # Camera device index (usually 0 for Pi Camera)
  resolution: [1920, 1080]  # Capture resolution [width, height]
  capture_frames: 5         # Number of frames to capture per brick
  motion_threshold: 2500    # Pixel difference threshold for motion detection
  motion_roi: [400, 200, 1100, 800]  # Region of interest [x1, y1, x2, y2]
  warmup_frames: 30         # Frames to skip on startup for auto-exposure
  led_pin: 12               # GPIO PWM pin for LED brightness
  led_brightness: 80        # LED brightness 0-100 percent
  # Optional secondary camera for multi-angle classification
  secondary_camera:
    enabled: false           # Set true to enable side-view camera
    camera_index: 1          # Device index for secondary camera
    resolution: [1280, 720]  # Secondary camera resolution

# ── BRICKOGNIZE API ─────────────────────────────────────────
classifier:
  api_url: "https://api.brickognize.com/predict/"
  confidence_threshold: 0.65  # Minimum confidence to accept classification
  timeout_seconds: 10         # API request timeout
  retry_count: 2              # Number of retries on failure
  unknown_bin: 31             # Bin number for unrecognized bricks (0-indexed)
  # Confidence-based routing — uncertain parts go to review bin
  review_bin_enabled: true       # Enable review bin for mid-confidence parts
  review_threshold: 0.45         # Conf below this = unknown; above this but below
                                 # confidence_threshold = review; above = accept
  review_bin: 30                 # Bin for parts needing manual review
  # Local cache — learns part signatures to skip API calls for common bricks
  local_cache_enabled: true          # Enable local signature cache
  local_cache_path: "local_cache.json"  # Where to store learned signatures
  local_cache_learn_threshold: 0.85  # Min API confidence to learn a part
  local_cache_max_size: 200          # Max cached signatures

# ── GATE TREE (SORTING) ────────────────────────────────────
sorter:
  i2c_bus: 1                  # I2C bus number (1 for Pi 5)
  pca9685_addresses: [0x40, 0x41]  # I2C addresses for the two PCA9685 boards
  servo_freq: 50              # Servo PWM frequency (Hz)
  servo_min_pulse: 150        # Min pulse width (0 degrees)
  servo_max_pulse: 600        # Max pulse width (180 degrees)
  left_angle: 30              # Servo angle for "left" path (degrees)
  right_angle: 150            # Servo angle for "right" path (degrees)
  gate_settle_ms: 120         # Time to wait for servos to reach position
  num_bins: 32                # Total output bins
  num_levels: 5               # Gate tree depth (2^5 = 32)
  # Power sequencing — GPIO pin to enable servo power relay after boot
  servo_power_pin: 22         # GPIO pin controlling servo power relay
  # Metal-gear servos — MG90S on top N levels for durability
  mg_servo_levels: 3          # Top 3 levels (7 gates) use MG90S servos
  mg_servo_min_pulse: 500     # MG90S min pulse width
  mg_servo_max_pulse: 2400    # MG90S max pulse width
  # Bin monitoring
  bin_full_threshold: 50      # Warn when a bin has this many bricks
  # Sort mode: 'part' (by part type), 'color', 'category', 'set'
  sort_mode: "part"
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

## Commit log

2026-03-14 Add LEGO AI Sorter v3 codebase with updated README
    Includes full Python codebase (classifier, conveyor, sorter, inventory,
    web UI, logger), 3D printable parts (OpenSCAD), docs, and a comprehensive
    README covering all modules, features, API endpoints, and hardware specs.
    [accessories.scad, belt_rollers.scad, brackets.scad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]
2026-03-14 Add 3D rendered prototype preview image to README
    Rendered from OpenSCAD assembly scene (assembly_preview.scad) showing
    the full machine: aluminium frame, conveyor belt, scanning chamber with
    camera, electronics box, binary gate tree, and output bins.
    [assembly_preview.scad]
2026-03-14 Add animated brick journey GIF to README
    48-frame animation rendered from OpenSCAD (brick_journey.scad) showing
    a red LEGO brick travelling along the conveyor belt, through the scanning
    chamber, and down into an output bin via the binary gate tree.
    [brick_journey.scad]
2026-03-14 Add cross-section path diagram showing brick journey with arrows
    Machine is cut in half to reveal the interior. Red arrows trace the
    brick from the conveyor belt, through the scanning chamber, off the
    belt end, through the binary gate tree, and into an output bin.
    [path_diagram.scad]
2026-03-14 Add entry chute part and update cross-section diagram
    entry_chute.scad: new printable part (PETG, two halves, no supports)
    that catches bricks off the belt end, slopes them ~5.5° down a 145mm
    ramp, and funnels them into the gate tree root via a throat section.
    path_diagram.scad: updated to show the chute in cross-section (blue)
    and corrected brick path arrows — belt → catch wall → ramp → throat
    → gate root → gate L1 → gate L2 → bin.
    [entry_chute.scad, path_diagram.scad]
2026-03-14 Add v4 Hybrid design: carousel feeder + pancake stack distribution
    Combines the existing binary gate tree AI pipeline with two
    mechanical innovations from carousel/pancake-stack feeder research:
    Input: 4-platform rotating carousel replaces linear belt
    - Eliminates 5.5° ramp angle problem (tilt-to-dispense instead)
    - Natural singulation (one brick per platform)
    - Pipelined: load/image/process/dispense happen simultaneously
    - 80mm sphere size constraint on all platform openings
    Distribution: Pancake stack (8 bins) + 3-level mini gate tree (8 sub-bins)
    - 64 sort destinations using only 15 servos (vs 31 in v3)
    - Pancake stack routes by category; mini-tree routes by part size
    - S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
    [carousel_feeder.scad, hybrid_assembly.scad, pancake_stack.scad]
2026-03-14 Add engineering technical drawing (cross-section A-A, 1:4 scale)
    Two-view orthographic engineering drawing of the v4 Hybrid design:
    - Front elevation cross-section with dimension lines, section markers,
    diagonal hatching, and red centerlines
    - Plan view (top-down) showing carousel circle, pancake stack,
    scanning chamber, and gate tree footprints
    - 16-component numbered callout legend
    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
    [technical_drawing.scad]
